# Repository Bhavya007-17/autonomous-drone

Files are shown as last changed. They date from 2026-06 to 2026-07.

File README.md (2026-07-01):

# Drone Tracker

A palm-sized mini quadcopter that tracks humans and records 4K video — built around a SpeedyBee F7 Mini flight controller, GPS navigation, and a DJI Neo-inspired camera on a single-axis tilt gimbal.

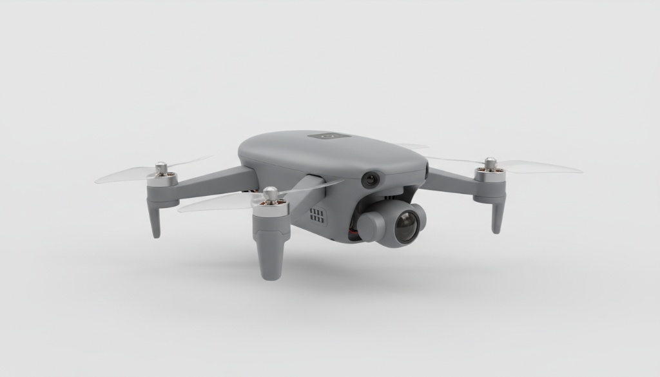
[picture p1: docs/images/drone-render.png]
Drone Tracker render









## Overview

**Drone Tracker** is a compact autonomous-tracking UAV platform. The airframe spans roughly **140 mm**, making it genuinely palm-sized while still carrying a full FPV stack, GPS module, and a gimbal-stabilized 4K camera.

The platform is designed for:

- **Human tracking** — GPS-assisted follow and position hold
- **4K video capture** — DJI Neo-inspired camera module with analog FPV feed
- **Dynamic framing** — single-axis tilt gimbal (SG90 servo) for pitch adjustment in flight
- **Manual + autonomous flight** — ELRS radio control with Betaflight firmware

## Key Specs

| Spec | Value |
|---|---|
| Frame size | ~140 mm (palm-sized) |
| Motors | 4× 1103 8000KV brushless |
| ESC | SpeedyBee BLS 35A 4-in-1 |
| Flight controller | SpeedyBee F7 Mini |
| Battery | 2S 350 mAh LiPo (14.8 V) |
| GPS | Be-180 Micro GPS |
| Camera | DJI Neo-inspired 1/2.3" CMOS, 4K |
| Gimbal | Single-axis tilt (SG90 servo) |
| Radio | ELRS 2.4 GHz Nano Receiver |
| VTX | RushFPV Tiny Tank |
| Firmware | Betaflight |
| Total parts | 33 (12 electrical + 21 mechanical) |
| Estimated BOM cost | **$412.83** |

## Design

### 3D CAD — Exploded View

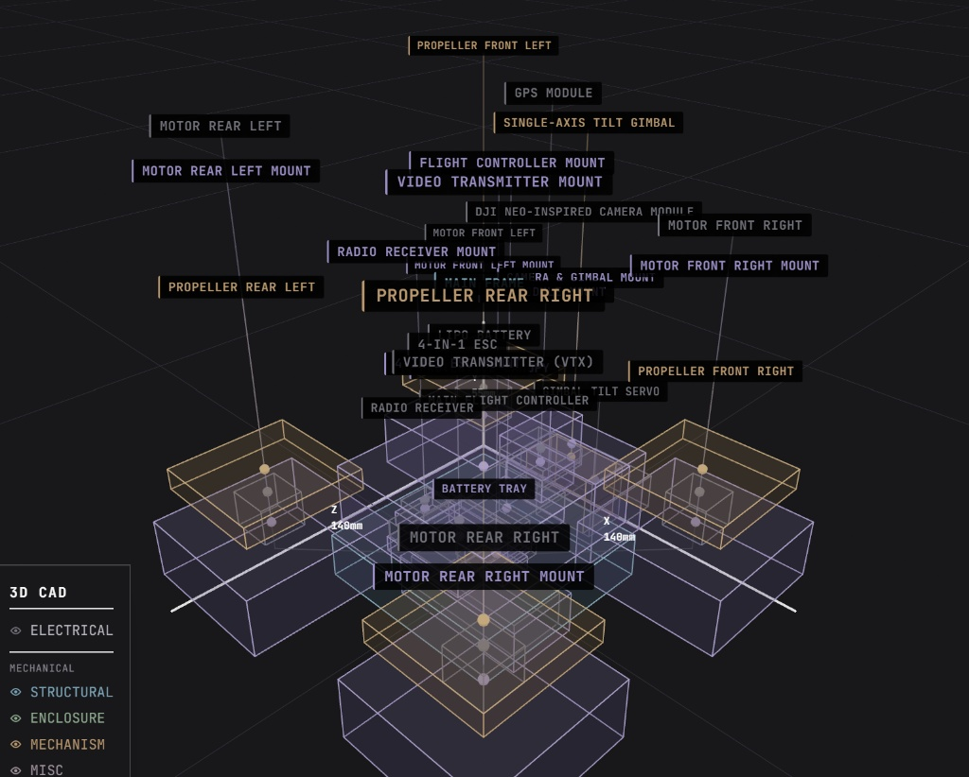
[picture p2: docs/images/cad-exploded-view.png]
CAD exploded view


The mechanical stack includes 3D-printed mounts for every subsystem — flight controller, ESC, GPS, radio, VTX, motors, camera/gimbal, battery tray, and a protective canopy. See [docs/parts-list.md](docs/parts-list.md) for the full bill of materials.

### Wiring Diagram

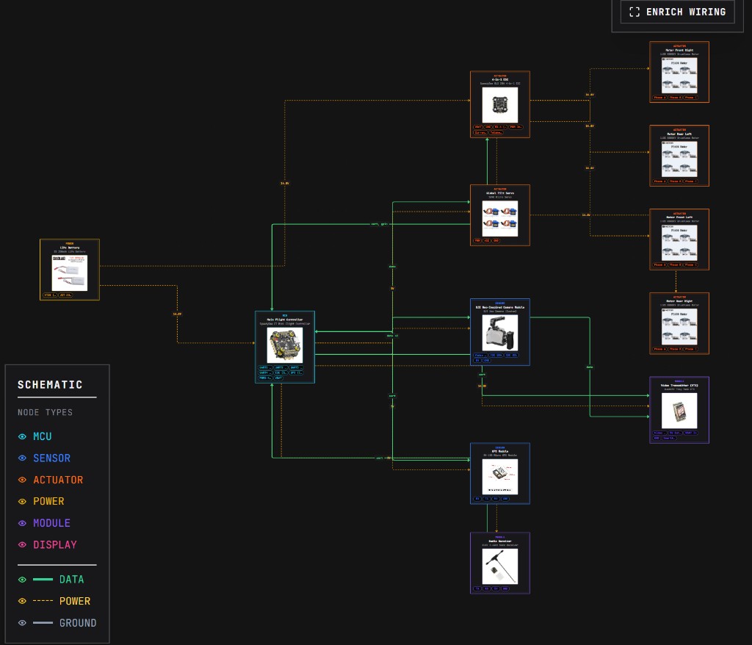
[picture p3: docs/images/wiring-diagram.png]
Wiring diagram


Central hub is the **SpeedyBee F7 Mini**. Power flows from a 2S LiPo through the 4-in-1 ESC to the motors; the FC distributes 5 V to peripherals over UART, I2C, and PWM. Full pin assignments are in [docs/wiring.md](docs/wiring.md).

## Structural FEA Analysis

Static-stress finite-element analysis of the **CINEC 25.1.2 cinewhoop airframe** (3D-printed ABS) in **Autodesk Fusion (Simulation)**, validating that the printed frame survives full-thrust loading. Full write-up, methodology, and high-resolution plots are in **[`structural-analysis/`](structural-analysis/)**.

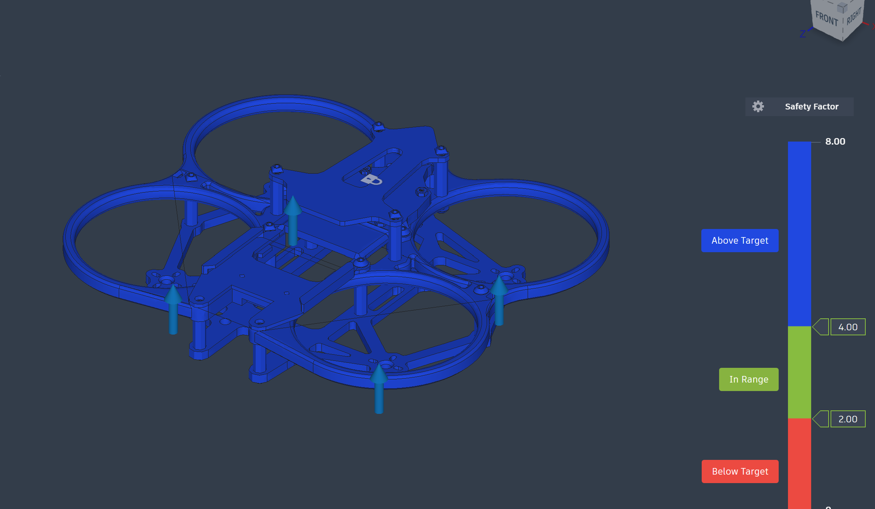
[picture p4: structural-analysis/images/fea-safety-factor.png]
Safety Factor result


| Result — 400 g total thrust (4 × 0.98 N) | Value |
|---|---|
| Minimum Safety Factor (ABS yield) | **10.2** — "Very strong" |
| Maximum von Mises stress | **1.96 MPa** |
| Maximum displacement | **1.18 mm** |
| Weakest zones | prop-guard spokes, duct-to-frame junctions |

**Method:** structural-parts-only model (non-load-bearing electronics removed), ABS material, *Fixed* constraint on the central top deck, four upward 0.98 N thrust loads at the motor bells, bonded automatic contacts, ~1.9 M-element tetrahedral mesh, solved locally. A frame-only baseline (Simulation Model 1) returned SF ≈ 0.57 — showing that the **ducts and prop guards act as primary load-sharing members**, not just protection.

→ **[Read the full structural analysis](structural-analysis/README.md)**

## Architecture

```
┌─────────────┐     UART2      ┌──────────┐
│  GPS Module │◄──────────────►│          │
└─────────────┘                │          │     PWM      ┌─────────┐
┌─────────────┐     UART3      │ SpeedyBee│────────────►│ 4-in-1  │──► Motors ×4
│ ELRS Radio  │◄──────────────►│ F7 Mini  │             │   ESC   │
└─────────────┘                │    FC    │     PWM5     └─────────┘
┌─────────────┐     I2C        │          │────────────► Gimbal Servo
│   Camera    │◄──────────────►│          │
└──────┬──────┘                │          │     UART4
       │ video                 └────┬─────┘────────────► VTX
       └────────────────────────────┘
```

1. **Sense** — IMU + barometer (onboard FC), GPS fix, camera feed
2. **Estimate** — Betaflight sensor fusion for attitude and position
3. **Control** — PID stabilization + position hold via GPS
4. **Track** — follow-target logic using GPS and visual cues (planned)
5. **Capture** — 4K recording with gimbal tilt for dynamic framing

## Build Guide

| Phase | Description | Doc |
|---|---|-----|
| 1. Fabricate | 3D print mounts, test-fit all parts | [assembly.md](docs/assembly.md#phase-1--fabricate) |
| 2. Wire | Solder power, motor, UART, I2C, PWM | [wiring.md](docs/wiring.md) |
| 3. Bring-up | Continuity checks, flash Betaflight, calibrate | [assembly.md](docs/assembly.md#phase-3--bring-up) |
| 4. Assemble | Mount electronics, route wires, install canopy | [assembly.md](docs/assembly.md#phase-4--assemble) |

### Tools

3D printer (PETG/PLA/TPU) · soldering iron · multimeter · wire strippers · M1.2/M2 drivers · LiPo charger · zip ties

## Repository Layout

```
autonomous-drone/
├── docs/
│   ├── images/
│   │   ├── drone-render.png        # product render
│   │   ├── wiring-diagram.png      # electrical schematic
│   │   └── cad-exploded-view.png   # 3D CAD exploded view
│   ├── parts-list.md               # full BOM (33 parts)
│   ├── wiring.md                   # pin map and connections
│   └── assembly.md                 # step-by-step build instructions
├── structural-analysis/            # FEA of the CINEC 25.1.2 frame
│   ├── README.md                   # full analysis write-up
│   ├── images/
│   │   ├── cad-assembly-iso.png    # CAD assembly, isometric view
│   │   ├── cad-assembly-top.png    # CAD assembly, top view
│   │   ├── cad-assembly-bottom.png # CAD assembly, bottom view
│   │   ├── fea-safety-factor.png   # Safety Factor plot
│   │   └── fea-von-mises-stress.png# von Mises stress plot
│   └── cinec-25-drone-model.stl    # 3D mesh of the drone
├── src/                             # flight firmware / tracking logic (planned)
└── README.md
```

## Roadmap

- [x] Frame and component selection
- [x] 3D CAD layout and wiring design
- [x] Parts list and assembly documentation
- [x] Structural FEA validation of the frame (min SF ≈ 10.2)
- [ ] 3D print and mechanical assembly
- [ ] Electrical bring-up and Betaflight tuning
- [ ] GPS waypoint navigation
- [ ] Human-tracking follow mode
- [ ] 4K video recording pipeline
- [ ] Field test + demo video

## Status

**Design + documentation complete** — mechanical CAD, wiring schematic, BOM, structural FEA, and bring-up procedures are documented. Hardware build and firmware development are next.

## License

MIT — see [LICENSE](LICENSE).

## Contact

Bhavya Dosi — [LinkedIn](https://www.linkedin.com/in/bhavya-dosi)

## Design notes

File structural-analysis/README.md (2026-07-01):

# CINEC 25.1.2 — Cinewhoop FPV Drone Frame · Structural FEA

Static-stress finite-element analysis of a 3D-printed **ABS ducted "cinewhoop" FPV drone frame**, performed in **Autodesk Fusion (Simulation)**. The study validates that the load-bearing structure survives full-thrust loading with margin, and identifies the highest-stress regions of the airframe.

| Isometric | Top | Bottom |
|---|---|---|
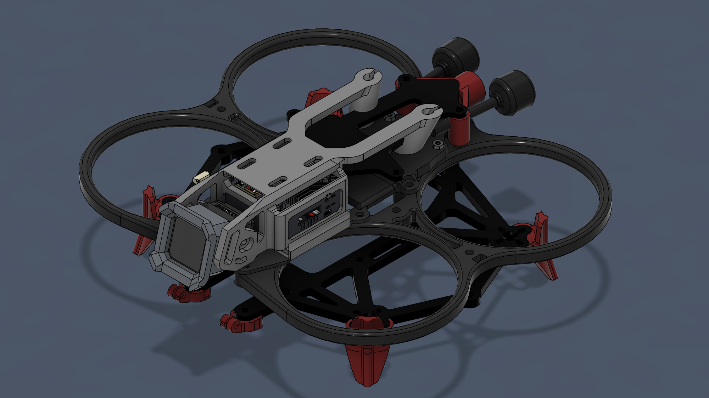
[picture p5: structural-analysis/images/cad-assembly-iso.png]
Isometric view
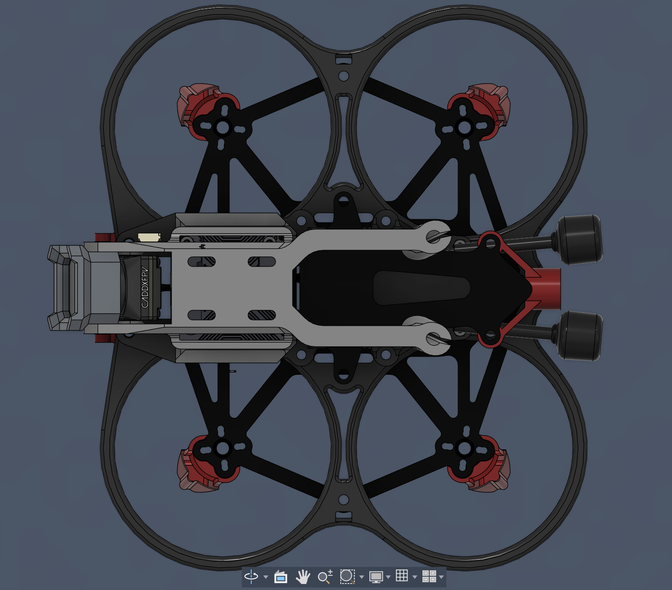
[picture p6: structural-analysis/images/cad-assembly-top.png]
Top view
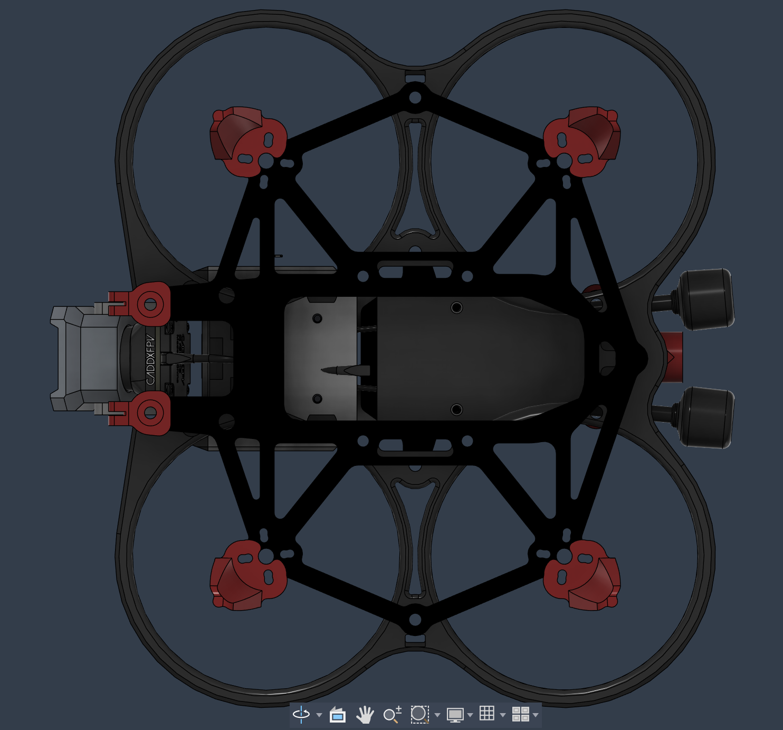
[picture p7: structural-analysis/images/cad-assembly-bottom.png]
Bottom view
|  |  |  |

---

## Overview

| | |
|---|---|
| **Airframe** | CINEC 25.1.2 — ducted cinewhoop, 4-motor |
| **Analysis type** | Linear static structural (Static Stress) |
| **Tool** | Autodesk Fusion — Simulation workspace |
| **Material** | ABS plastic (FDM), all structural parts |
| **Load case** | 400 g total thrust (4 × 100 g), motors at full pull |
| **Result** | Min. Safety Factor **10.2** · Max von Mises **1.955 MPa** · Max deflection **1.18 mm** |

The full CAD assembly (above) includes the frame, ducts and prop guards, standoffs, top deck, four XING2 1404 motors, an AIO flight controller, an ELRS receiver, camera, battery and capacitor. For the structural analysis, only the **load-bearing parts** were retained (see methodology).

---

## Objective

Confirm that the printed ABS airframe can carry the thrust produced by its four motors without yielding, and locate the weakest regions so the design can be reinforced or lightened intelligently.

---

## Methodology

### Model preparation
The complete design contains ~1,600 bodies. Bonded-contact FEA cannot connect free-floating electronics and fasteners, so the full assembly produced ~1,596 unconstrained groups and would not solve. The model was therefore reduced to **structural parts only**:

- **Kept:** central frame, ducts, prop guards, standoffs, top deck plate.
- **Removed:** motors, screws, battery, capacitor, receiver, and AIO electronics (non-structural, cannot be bonded).

One electronics body (the AIO flight-controller board) contained corrupted geometry that caused surface-meshing errors and was excluded with **Simplify → Remove**.

### Boundary conditions
- **Material:** ABS Plastic applied to every body (yield strength ≈ 20 MPa).
- **Constraint:** *Fixed* support on the central top deck plate (the mounting interface to the payload/stack).
- **Loads:** `0.98 N` (100 g) applied **upward (+Y)** at each of the **four motor-mount bell edges** → **400 g total thrust** (Force-Per-Entity). This represents roughly 2× hover thrust for a ~200 g all-up-weight micro craft — a conservative, aggressive-maneuver load.
- **Gravity:** suppressed, to isolate the structural response to thrust.
- **Contacts:** automatic bonded contacts at 2 mm tolerance.

### Mesh
- Solid tetrahedral mesh, **12 mm** absolute average element size (coarsened from the default to clear surface-meshing *geometry errors* around the center standoffs/deck).
- Solver mesh ≈ **1.91 M nodes / 1.33 M elements**.
- **"Remove rigid body modes"** enabled in the solver to stabilize a handful of disconnected non-load-bearing hardware bodies (otherwise the model is reported as statically unstable). This adds weak springs only to otherwise-free parts and does not affect the stress in the connected load path.

Solved locally (static solve — no cloud credits).

---

## Results

**Simulation Model 2 — full structural assembly**

| Quantity | Value |
|---|---|
| Minimum Safety Factor (yield) | **10.23** — "Very strong" |
| Maximum von Mises stress | **1.955 MPa** |
| Maximum total displacement | **1.183 mm** |
| Solver | Local static, ABS, bonded contacts |

### Safety Factor
Entire structure sits above the 4.0 "In Range" target (whole model reads blue / "Above Target" on the 0–8+ scale). Minimum SF ≈ 10.2 means the airframe carries roughly 10× its full-thrust load before reaching the ABS yield point.

Safety Factor result

### Von Mises Stress
Peak stress **1.955 MPa**, far below the ~20 MPa ABS yield point. Elevated stress (cyan/green against the blue field) concentrates on the **prop-guard spoke arms** and the **duct-to-frame / standoff junctions** — the members that transfer motor thrust into the central frame.

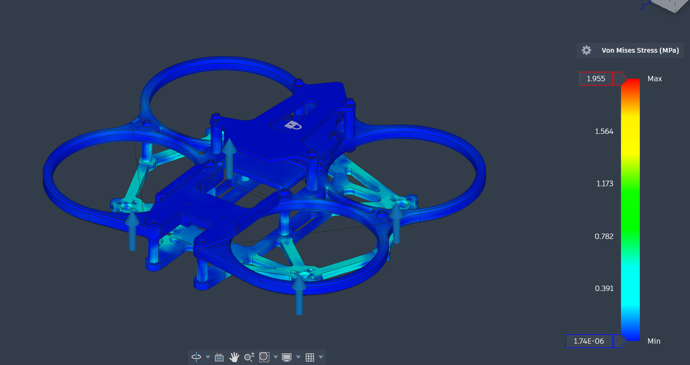
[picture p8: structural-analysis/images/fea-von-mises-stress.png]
Von Mises stress result


### Displacement
Peak deflection **1.183 mm**, at the **outer duct / prop-guard rings** (furthest from the fixed central deck). The core frame is essentially rigid; flex lives in the cantilevered duct rings. *(Displacement contour plot to be re-captured and added — numeric result from the solver report is final.)*

---

## Interpretation

**Weakest zones**
1. Prop-guard spoke arms (thin X-struts inside each duct).
2. Duct-to-frame and standoff junctions near the center.
3. Outer duct rings — highest deflection, though low stress.

The load path is intact and continuous: thrust at the motor bells → through the ducts and spokes → into the central frame → reacted at the fixed top deck. Stress is low and well distributed, so the airframe is **over-built for this load case** — there is room to lighten the ducts/guards if mass reduction is a goal.

**Frame-only vs. full-structure (Model 1 vs. Model 2)**

An earlier study on the **bare central frame arms alone** (Simulation Model 1) returned a minimum Safety Factor of **≈ 0.571** — i.e. localized yielding under the same 400 g thrust. When the **full bonded structure** (ducts + prop guards + standoffs + deck, this study, Model 2) shares the load, the min SF rises to **≈ 10.2**.

The two numbers bracket the design:
- **0.571** — worst-case lower bound if the slim frame arms had to carry thrust in isolation.
- **10.2** — realistic behavior of the fully-assembled ducted structure, where many redundant paths carry the load.

This is the key structural insight: the **ducts and prop guards are not just cosmetic/protective — they are primary load-sharing members** that make the airframe stiff.

---

## Assumptions & limitations

- **Linear static** analysis (small deflection, linear-elastic ABS) — no impact, fatigue, vibration, or modal/resonance analysis.
- FDM parts are **anisotropic**; this model treats ABS as isotropic with bulk properties, so layer-adhesion weakness (Z-direction) is not captured.
- **Bonded** contacts assume glued/press-fit interfaces; real bolted joints may behave differently.
- Static 2× hover thrust load only — real flight adds gyroscopic, gust and crash loads.
- "Remove rigid body modes" stabilizes minor disconnected hardware; results are valid for the connected load-bearing structure.

---

## Repository contents

| File | Description |
|---|---|
| `images/cad-assembly-iso.png` | Full CINEC 25.1.2 CAD assembly — isometric view |
| `images/cad-assembly-top.png` | Full CAD assembly — top view |
| `images/cad-assembly-bottom.png` | Full CAD assembly — bottom view |
| `images/fea-safety-factor.png` | FEA — Safety Factor contour plot |
| `images/fea-von-mises-stress.png` | FEA — von Mises stress contour plot |
| `cinec-25-drone-model.stl` | 3D mesh of the full drone (mm) |
| `README.md` | This report |

---

## Tools

Autodesk Fusion (Design + Simulation) · Linear static FEA · ABS (FDM) material model

*Analysis and documentation for the CINEC 25.1.2 cinewhoop airframe.*

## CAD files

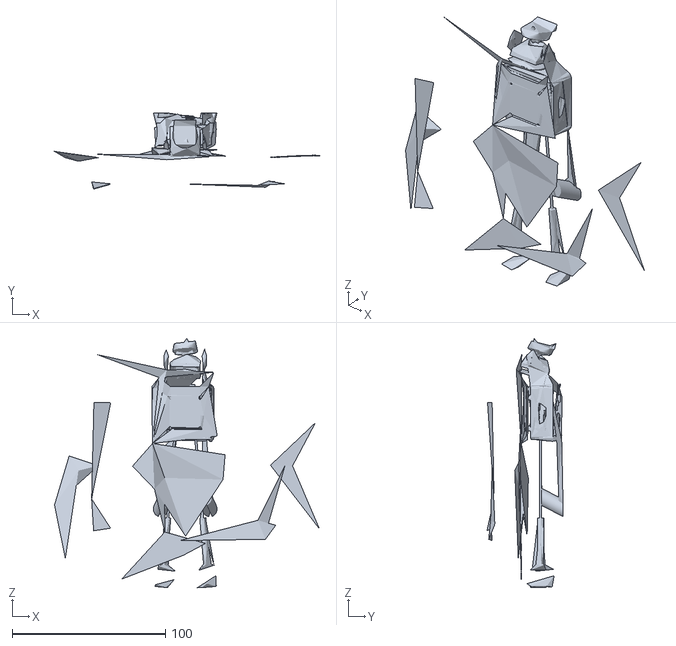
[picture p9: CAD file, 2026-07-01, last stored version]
autonomous-drone-reorganized/autonomous-drone/structural-analysis/cinec-25-drone-model.stl
172.9 x 49.7 x 162.8

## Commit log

2026-06-10 docs: add Drone Tracker README, BOM, wiring, and assembly guides
    Document the palm-sized human-tracking mini drone with full parts list, wiring schematic, 3D CAD images, and step-by-step build instructions.
2026-07-01 Add structural FEA of CINEC 25.1.2 frame (report, result plots, STL)
    [cinec-25-drone-model.stl]
2026-07-01 docs: add Structural FEA section to README (CINEC 25.1.2 frame results)
2026-07-01 docs: fix structural-analysis screenshots, reorganize FEA images into images/
    [cinec-25-drone-model.stl]
2026-07-01 chore: clean up nested folder and stray zip from reorg upload, finalize structural-analysis reorganization
    [cinec-25-drone-model.stl]
